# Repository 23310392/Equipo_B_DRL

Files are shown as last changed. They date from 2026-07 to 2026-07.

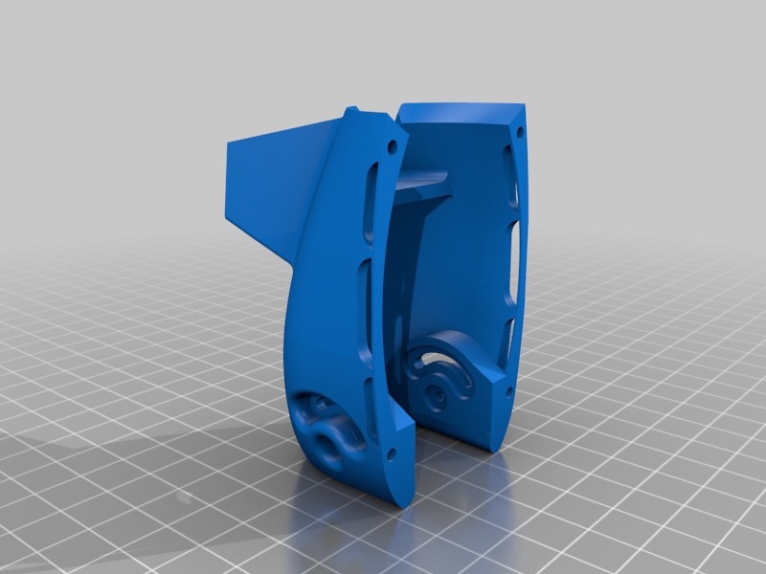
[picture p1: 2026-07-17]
Diseño 3D/Imagenes_Piezas_Diseño/6f083358760ed6dc125744b1c3c0a0e9.png

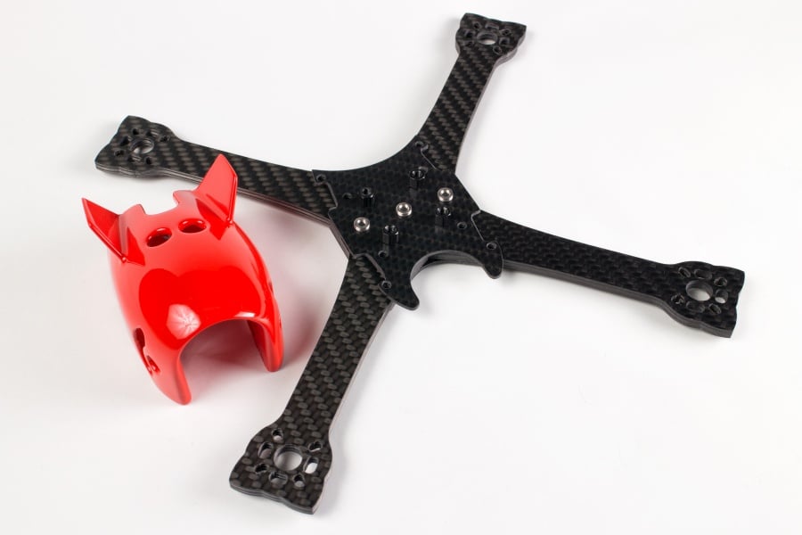
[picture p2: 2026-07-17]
Diseño 3D/Imagenes_Piezas_Diseño/IMG_6907.jpg

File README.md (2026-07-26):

<div align="justify">

# N.E.R.V. Protocol

INTEGRANTES:

* COVARRUBIAS SÁNCHEZ ESTEFHANY BETZABE - 23310387
* CORTES VILLA DANIEL - 23310392
* DURAN DE HUERTA JIMENEZ ALEX - 23310378
* FLORES GONZALEZ BYRON ZADQUIEL - 23310338
* TORRES HERNANDEZ ELIAS URIEL - 23310395

# Proyecto: Dron FPV Modificado (Ingeniería Inversa E88)

Este repositorio documenta todo el proceso de diseño, análisis, configuración y ensamblaje de un dron FPV personalizado. Este proyecto nace a partir de la aplicación de ingeniería inversa a un dron comercial modelo E88, con el objetivo de mejorar sus características de vuelo, adaptarlo para FPV (First Person View) y optimizar su rendimiento general.

---

## 📐 Diseño y Decisiones Estructurales

En esta sección se documentan las decisiones de diseño tomadas para llegar a la versión final del chasis y la distribución de componentes. 

<p align="justify">
<strong>MARK I</strong><br>
<strong>Reducción de peso y distribución de masa:</strong> El chasis fue diseñado con dimensiones inferiores a 5 pulgadas, optimizando la geometría para reducir el peso sin comprometer la rigidez estructural. La distribución de la masa se concentró en la parte central del dron para favorecer la estabilidad y mejorar la respuesta durante el vuelo.<br>
<strong>Materiales:</strong> El diseño está pensado para ser fabricado mediante impresión 3D en ABS, material que ofrece una buena relación entre resistencia mecánica, durabilidad y facilidad de fabricación. Esto permite obtener un prototipo ligero, resistente y de bajo costo para pruebas y validación.<br>
<strong>Integración de la electrónica:</strong> Este primer diseño se enfocó principalmente en el desarrollo de la estructura mecánica. No se definieron alojamientos ni puntos de montaje específicos para los componentes electrónicos, por lo que durante el ensamblaje se identificó que elementos como la batería, el Arduino Nano ESP32, el MPU6050, los ESC, el cableado y otros componentes no contaban con el espacio necesario para una integración adecuada. Estas limitaciones sirvieron como base para el rediseño de versiones posteriores.
</p>

<p align="center">
  Mark I
</p>

<p align="justify">
<strong>MARK II</strong><br>
<strong>Reducción de peso y distribución de masa:</strong> Para esta segunda iteración se realizó un rediseño completo del chasis tomando como referencia la arquitectura empleada en drones FPV de menos de 5 pulgadas. Se adoptó una configuración compuesta por una placa inferior, una cubierta superior y separadores, lo que permitió obtener una estructura más rígida y modular. Además, se buscó concentrar la mayor parte de la masa en la zona central del dron con el objetivo de mejorar la estabilidad, disminuir el momento de inercia y facilitar futuras tareas de mantenimiento y sustitución de componentes.<br>
<strong>Materiales:</strong> Al igual que en el MARK I, el prototipo fue diseñado para ser fabricado mediante impresión 3D en ABS. La elección de este material respondió a su buena resistencia mecánica, su capacidad para soportar impactos moderados y las temperaturas generadas durante la operación de los componentes electrónicos. Asimismo, el uso de impresión 3D permitió fabricar y evaluar rápidamente nuevas iteraciones del diseño, reduciendo los tiempos de desarrollo y el costo de fabricación de los prototipos.<br>
<strong>Diseño estructural:</strong> Durante esta iteración se incorporaron características propias de los chasis utilizados en drones FPV comerciales. Entre ellas destacan el soporte frontal para el montaje de la cámara, una cubierta superior desmontable para facilitar el acceso a la electrónica y una estructura interna pensada para organizar los diferentes módulos del sistema. Estas modificaciones representaron un avance significativo respecto al MARK I, ya que permitieron obtener un diseño más compacto, estético y cercano a una solución funcional.<br>
<strong>Integración de la electrónica:</strong> Una de las principales mejoras del MARK II fue la incorporación de espacios destinados al montaje de la batería y otros componentes electrónicos. Sin embargo, durante el proceso de ensamblaje se identificó que las dimensiones utilizadas durante el modelado no coincidían con las medidas reales de varios de estos componentes. Como consecuencia, algunos elementos no podían instalarse correctamente o requerían modificaciones adicionales para su montaje. Esta situación evidenció la importancia de realizar un levantamiento dimensional más preciso antes de la etapa de diseño, así como de considerar tolerancias de fabricación y ensamblaje. Las observaciones obtenidas durante esta fase sirvieron como base para el desarrollo del MARK III, donde se redimensionaron los compartimientos internos y se optimizó la distribución de los componentes para garantizar una integración adecuada.
</p>

<p align="center">
  Mark II
</p>

<p align="justify">
<strong>MARK III</strong><br>
<strong>Reducción de peso y distribución de masa:</strong> A diferencia de las iteraciones anteriores, en este diseño se decidió abandonar la restricción de construir un dron con dimensiones inferiores a 5 pulgadas. Durante el desarrollo se comprobó que los componentes electrónicos seleccionados requerían un mayor espacio para su integración, por lo que mantener ese límite comprometía tanto el ensamblaje como la distribución del peso. Como resultado, se diseñó un chasis completamente nuevo, con dimensiones personalizadas que permitieran alojar todos los componentes sin afectar la estabilidad ni la accesibilidad. La nueva distribución de masa se centró en mantener el centro de gravedad lo más cercano posible al eje del dron, favoreciendo un comportamiento estable durante el vuelo.<br>
<strong>Materiales:</strong> El chasis continúa siendo fabricado mediante impresión 3D en ABS, material seleccionado por su resistencia mecánica, durabilidad y facilidad de fabricación. El uso de este material permitió mantener un peso estructural relativamente bajo, además de facilitar la fabricación de piezas personalizadas y futuras modificaciones sin incrementar significativamente los costos del proyecto.<br>
<strong>Diseño estructural:</strong> El MARK III representa un rediseño completo respecto a los prototipos anteriores. Tanto la geometría como las dimensiones fueron desarrolladas específicamente para satisfacer las necesidades del proyecto, sin seguir estrictamente las medidas convencionales de los drones FPV comerciales. Se priorizó la funcionalidad sobre el tamaño, obteniendo un chasis más amplio que proporciona una mejor distribución interna, mayor facilidad de ensamblaje y acceso a los componentes para tareas de mantenimiento. Aunque sus dimensiones son mayores que las de los prototipos MARK I y MARK II, el diseño mantiene una estructura robusta, práctica y cómoda para su manipulación.<br>
<strong>Integración de la electrónica:</strong> Todas las dimensiones del chasis fueron ajustadas tomando como referencia las medidas reales de los componentes electrónicos. Esto permitió integrar correctamente la batería, el Arduino Nano ESP32, el MPU6050, los ESC, los motores, el sistema de distribución del cableado y los demás elementos necesarios para el funcionamiento del dron. A diferencia de las versiones anteriores, todos los componentes pueden instalarse sin interferencias mecánicas, facilitando el ensamblaje y el mantenimiento del sistema.<br>
<strong>Peso del prototipo:</strong> El chasis impreso y completamente ensamblado presenta un peso aproximado de 337 g. Una vez instalados todos los componentes electrónicos, el peso total del dron permanece por debajo de los 950 g, cumpliendo con el objetivo de mantener una plataforma suficientemente ligera para operar sin comprometer la resistencia estructural. Este equilibrio entre peso, espacio disponible y robustez convierte al MARK III en el diseño final del proyecto y en la versión que satisface completamente los requerimientos establecidos por el equipo.
</p>

---

## 📈 Modelado Matemático y Simulación en MATLAB

<p align="justify">
Para comprender el comportamiento dinámico del dron y predecir su respuesta a los comandos de control, se desarrolló un modelo matemático en MATLAB. A continuación se presenta la evidencia fotográfica y gráfica de las ondas de comportamiento de nuestro modelo (por ejemplo, respuesta al escalón, ajuste de PIDs teórico, estabilización de altitud).
</p>

### Diagrama de control
<p align="center">
  Diagrama de control
</p>

<p align="justify">
Este diagrama implementa un <strong>sistema de control en cascada</strong> para la estabilización y seguimiento de trayectoria de un modelo no lineal de 6 grados de libertad (<code>Modelo_NERV</code>) en Simulink.
</p>

### 📐 Arquitectura del Sistema
* **Control de Posición (Lazos Externos):** Regula las coordenadas de translación en los ejes $X$, $Y$ y la altura ($Z$), generando las referencias de actitud correspondientes.
* **Control de Actitud (Lazos Internos):** Estabiliza la orientación del vehículo gestionando los ángulos de **Roll** ($\phi$), **Pitch** ($\theta$) y **Yaw** ($\psi$).
* **Planta No Lineal:** Integra la dinámica de vuelo de 6-DOF (`Modelo_NERV`) junto con bloques de integración temporal y realimentación de estados.
* **Visualización:** Monitoreo en tiempo real de la posición espacial y el comportamiento de los ángulos de Euler mediante bloques *Scope*.

### Gráficas de movimiento (X, Y, Z, Roll, Pitch y Yaw)
<p align="justify">
<strong>Movimiento en X</strong>: Representa el desplazamiento lineal en el eje X. Se observa una transición limpia y rápida que alcanza la posición objetivo de 2m sin sobreimpulsos agresivos.
</p>
<p align="center">
  Gráfica de movimiento en X
</p>

<p align="justify">
<strong>Movimiento en Y</strong>: Muestra la respuesta en el eje Y alcanzando de forma estable y asintótica el valor de referencia configurado en 1m.
</p>
<p align="center">
  Gráfica de movimiento en Y
</p>

<p align="justify">
<strong>Movimiento en Z (Altura)</strong>: Muestra la respuesta escalón de la altitud del cuadricóptero. Presenta un ligero sobreimpulso controlado durante los primeros segundos antes de estabilizarse suavemente en la referencia deseada de 2m.
</p>
<p align="center">
  Gráfica de movimiento en Z
</p>

<p align="justify">
<strong>Ángulo Pitch</strong>: Ilustra la evolución del ángulo de cabeceo. Exhibe un pequeño transitorio inicial debido al acoplamiento dinámico antes de asentarse de manera completamente horizontal en estado estacionario.
</p>
<p align="center">
  Gráfica de ángulo Pitch
</p>

<p align="justify">
<strong>Ángulo Roll</strong>: Muestra el comportamiento del ángulo de alabeo. Presenta la compensación inicial de la inclinación lateral correspondiente al acoplamiento de los ejes antes de mantenerse estable en 0°.
</p>
<p align="center">
  Gráfica de ángulo Roll
</p>

<p align="justify">
<strong>Ángulo Yaw</strong>: Refleja la orientación del ángulo de guiñada, el cual converge de forma uniforme y estable hacia el valor de referencia establecido.
</p>
<p align="center">
  Gráfica de movimiento en Y
</p>

---

## ⚡ Electrónica y Protocolos de Comunicación

<p align="justify">
La transformación del E88 a un dron FPV funcional requirió una actualización completa de la electrónica y la implementación de protocolos de comunicación robustos.
</p>

### Componentes Principales
*   **Controladora de Vuelo (FC):** [Sensor MPU6050]
*   **Variadores de Velocidad (ESC):** [ESCs 30A]
*   **Motores:** [2212 1000KV]
*   **Receptor :** [Arduino nano ESP32]

### Protocolos de Comunicación Utilizados
*   **Receptor a Controladora (Arduino nano ESP32 -> dispositivo conectado por wifi):** El protocolo más común para conectar un Arduino Nano ESP32 a un dispositivo vía Wi-Fi y controlar un dron es el uso de comunicación basada en UDP/TCP sobre la red inalámbrica, donde el ESP32 actúa como punto de acceso o cliente y recibe comandos de control (pitch, roll, yaw, throttle) enviados desde un smartphone o computadora. Esto permite transmitir órdenes en tiempo real con baja latencia.
*   **Controladora(Arduino nano ESP32) a ESCs:** La comunicación entre el Arduino Nano ESP32 y los ESCs de 30A se realiza de forma simple y eficiente mediante PWM, permitiendo controlar la velocidad de los motores y, con ello, la estabilidad y maniobrabilidad del dron.
*   **Sensores Internos (Acelerómetro):**
  * El **MPU6050** integra un acelerómetro de 3 ejes que mide las aceleraciones lineales en tiempo real.
  * Permite detectar cambios en la posición y movimiento del dron, fundamentales para calcular la orientación (roll, pitch).
  * Su comunicación mediante protocolo **I²C** (líneas SDA y SCL) simplifica la conexión con el **Arduino Nano ESP32**.
  * El acelerómetro trabaja junto con el giroscopio para reducir errores de deriva y mejorar la precisión de los cálculos de estabilidad.

## Reporte de materiales y justificación

## Sensor MPU6050
### Descripción
<p align="justify">
El MPU6050 es un módulo que integra un acelerómetro de 3 ejes y un giroscopio de 3 ejes, ofreciendo un sistema de medición de 6 grados de libertad (6DOF). Se utiliza ampliamente en proyectos de drones por su capacidad de medir aceleraciones lineales y velocidades angulares en tiempo real.
</p>

### Justificación de uso en el dron
- Permite obtener datos de orientación y movimiento (roll, pitch, yaw).
- Mejora la estabilidad del vuelo, corrigiendo oscilaciones y vibraciones.
- Facilita la implementación de controladores PID, ajustando la velocidad de los motores para mantener equilibrio.
- Incluye un Digital Motion Processor (DMP) que procesa cálculos de orientación dentro del chip, reduciendo la carga del microcontrolador.
- Se comunica mediante I²C, lo que simplifica la integración con placas como Arduino o ESP32.

### Beneficios en la mejora del dron
- Vuelo más estable y controlado.
- Maniobras más suaves y precisas.
- Reducción de errores por deriva del giroscopio mediante fusión de datos con el acelerómetro.
- Flexibilidad para integrarse con otros sensores (GPS, barómetro, magnetómetro).

---

## Placa de desarrollo Arduino Nano ESP32
### Descripción
<p align="justify">
El Arduino Nano ESP32 es una placa compacta que combina la facilidad de uso del ecosistema Arduino con la potencia del microcontrolador ESP32. Ofrece conectividad inalámbrica integrada (Wi-Fi y Bluetooth), múltiples entradas/salidas digitales y analógicas, y capacidad de procesamiento superior en comparación con placas tradicionales como el Arduino Nano clásico.
</p>

### Justificación de uso en el dron
- Actúa como unidad de control principal, gestionando la lectura de sensores y el envío de señales a los motores.
- Su procesador dual-core permite ejecutar algoritmos de control en tiempo real, como filtros de fusión de datos y controladores PID.
- La conectividad Wi-Fi/Bluetooth facilita la comunicación remota para telemetría, control desde aplicaciones móviles o transmisión de datos.
- Compatible con librerías y entornos de programación de Arduino, lo que simplifica el desarrollo y la integración con otros módulos.
- Su tamaño reducido y bajo consumo energético lo hacen ideal para aplicaciones en drones ligeros.

### Beneficios en la mejora del dron
- Mayor capacidad de procesamiento para cálculos de estabilidad y navegación.
- Posibilidad de implementar funciones avanzadas como control remoto inalámbrico o envío de datos en tiempo real.
- Integración sencilla con sensores como el MPU6050, GPS y módulos de comunicación.
- Optimización del espacio y peso gracias a su formato compacto.
- Es un componente de bajo costo y alta disponibilidad, ideal para proyectos académicos y prototipos.

---

## Controlador de velocidad electrónico (ESC) 30A
### Descripción
<p align="justify">
El ESC de 30 amperios (30A) es un controlador de velocidad electrónico diseñado para regular la potencia suministrada a los motores brushless del dron. Convierte la señal de control proveniente del microcontrolador (Arduino Nano ESP32) en pulsos eléctricos adecuados para ajustar la velocidad y dirección de los motores.
</p>

### Justificación de uso en el dron
- Permite un control preciso de la velocidad de los motores, esencial para la estabilidad y maniobrabilidad del dron.
- Soporta hasta 30 amperios de corriente, adecuado para motores de tamaño medio utilizados en drones académicos o recreativos.
- Incluye funciones de protección contra sobrecorriente y sobrecalentamiento, aumentando la seguridad del sistema.
- Compatible con señales PWM estándar, facilitando la integración con placas de control como el Arduino Nano ESP32.
- Su tamaño compacto y peso ligero lo hacen ideal para aplicaciones aéreas.

### Beneficios en la mejora del dron
- Mejora la respuesta dinámica del dron al ajustar rápidamente la velocidad de los motores.
- Contribuye a un vuelo más estable y seguro, evitando daños por sobrecarga eléctrica.
- Permite implementar algoritmos de control avanzados (PID) para mantener equilibrio y realizar maniobras suaves.
- Asegura una distribución eficiente de energía, optimizando el rendimiento de la batería.

---

## Motor Brushless 2212 1000KV
### Descripción
<p align="justify">
El motor brushless 2212 1000KV es un motor eléctrico sin escobillas diseñado para aplicaciones aéreas como drones y cuadricópteros. El valor 1000KV indica que el motor gira aproximadamente a 1000 revoluciones por minuto (RPM) por cada voltio aplicado, lo que lo hace adecuado para un equilibrio entre potencia y eficiencia.
</p>

### Justificación de uso en el dron
- Proporciona la fuerza de empuje necesaria para levantar y mantener el dron en vuelo.
- Su diseño sin escobillas (brushless) ofrece mayor durabilidad, menor mantenimiento y mejor eficiencia energética en comparación con motores con escobillas.
- El rango de 1000KV es ideal para drones de tamaño medio, ya que permite un buen control de velocidad y estabilidad sin sacrificar autonomía.
- Compatible con controladores ESC de 30A, asegurando una integración confiable en el sistema de propulsión.
- Su tamaño compacto y peso ligero lo hacen adecuado para estructuras de drones académicos y recreativos.

### Beneficios en la mejora del dron
- Vuelo más estable y eficiente, gracias a su respuesta rápida y precisa.
- Mayor tiempo de vuelo, al optimizar el consumo de energía de la batería.
- Capacidad de carga adecuada, permitiendo transportar sensores y componentes adicionales sin comprometer el rendimiento.
- Durabilidad y confiabilidad.

---

## 💻 Programación y Lógica de Vuelo (Custom Firmware)

<p align="justify">
El "cerebro" de este dron no utiliza un firmware comercial prefabricado, sino que funciona con un controlador de vuelo personalizado programado desde cero para el microcontrolador ESP32.
</p>

* **Estación de Control Terrestre (Interfaz Web y WebSockets):** Para este proyecto, decidimos prescindir de un radio control físico tradicional debido a limitaciones de tiempo y presupuesto. En su lugar, el ESP32 está configurado como un Punto de Acceso (AP) que genera su propia red Wi-Fi y aloja una interfaz web construida en HTML, CSS y JavaScript. Elegimos esta arquitectura web por su inmensa practicidad y facilidad de implementación: nos permite pilotar el dron desde cualquier smartphone directamente en el navegador, sin necesidad de instalar aplicaciones de terceros. Para garantizar que los movimientos de los joysticks virtuales lleguen al dron sin retrasos perceptibles, la comunicación bidireccional se realiza mediante el protocolo WebSockets.

* **Fusión de Sensores (Filtro Complementario):** Para que el dron "sienta" su orientación en el espacio, el ESP32 se comunica mediante el protocolo I2C con un sensor IMU MPU-6050. El código implementa un Filtro Complementario matemático que fusiona las lecturas rápidas del giroscopio con la referencia absoluta de la gravedad del acelerómetro, eliminando el ruido mecánico y el drift (desviación) a lo largo del tiempo.

* **Lazo de Control PID:** El corazón del vuelo autónomo es nuestro bucle PID (Proporcional, Integral, Derivativo), diseñado para ejecutarse a alta velocidad (aprox. 100Hz). El código compara constantemente la orientación real del dron (medida por el MPU-6050) con la orientación deseada por el piloto en la interfaz web. El PID calcula instantáneamente la compensación necesaria en los ejes de Cabeceo (Pitch), Alabeo (Roll) y Guiñada (Yaw) para corregir cualquier desviación.

* **Matriz de Mezcla de Motores (Mixer Quad-X):** Basándonos en la cinemática estándar de los drones cuadricópteros, los resultados del cálculo PID se introducen en un algoritmo de mezcla de motores. Este sistema distribuye matemáticamente la potencia necesaria a cada uno de los cuatro motores de forma independiente mediante señales PWM. Esto permite que el dron contrarreste la gravedad, obedezca los comandos direccionales y se estabilice a sí mismo frente a perturbaciones externas.

---

## 📸 Galería del Modelo Físico

<p align="justify">
En esta sección se muestra el resultado final del ensamblaje del dron, detallando el empaquetado de los componentes, la gestión de cables (cable management) y la estética final de la aeronave.

<p align="center">
WhatsApp Image 2026-07-25 at 9 10 56 PM
</p>
</p>

---

## Documento Post Mortem

<p align="justify">
Para la información completa de las fallas principales que presentó el dron MARK III y la razón de porqué no se logró realizar un vuelo de "hover", consulte el siguiente link:  <a href="./Post Mortem.md">Documento Post Mortem</a>. 
</p>
</div>

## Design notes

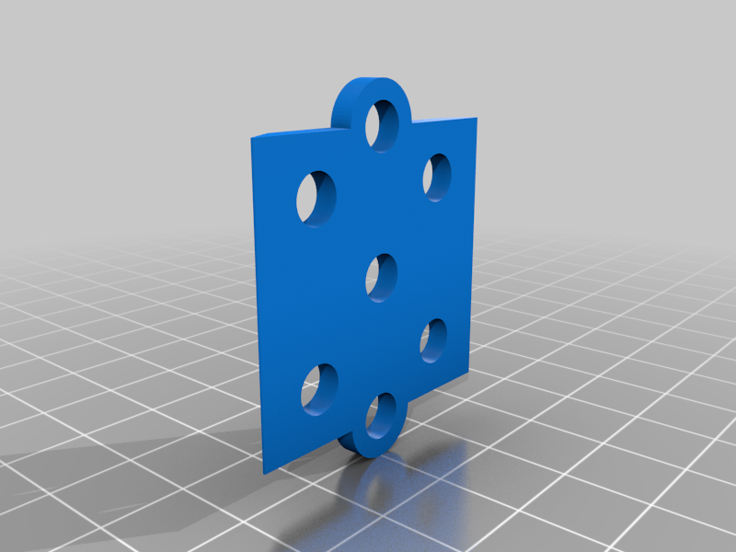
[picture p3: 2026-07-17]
Diseño 3D/Imagenes_Piezas_Diseño/4b94d525dbd86995620f139ecef4ba84.png

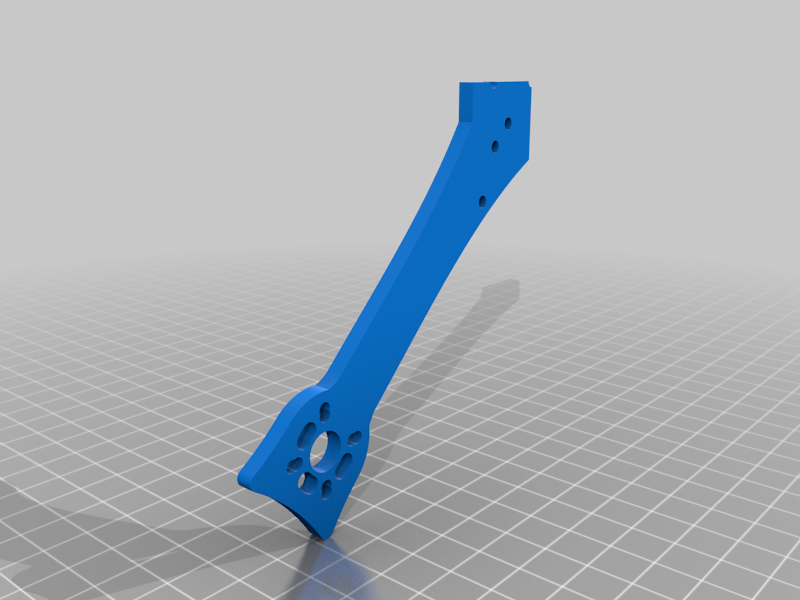
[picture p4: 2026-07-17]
Diseño 3D/Imagenes_Piezas_Diseño/7501a97a94f46a22147aaab2897a6f8f.png

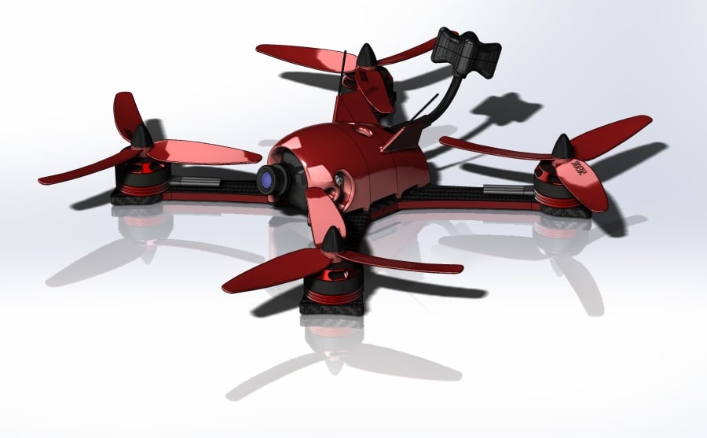
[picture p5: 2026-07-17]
Diseño 3D/Imagenes_Piezas_Diseño/3D.jpg

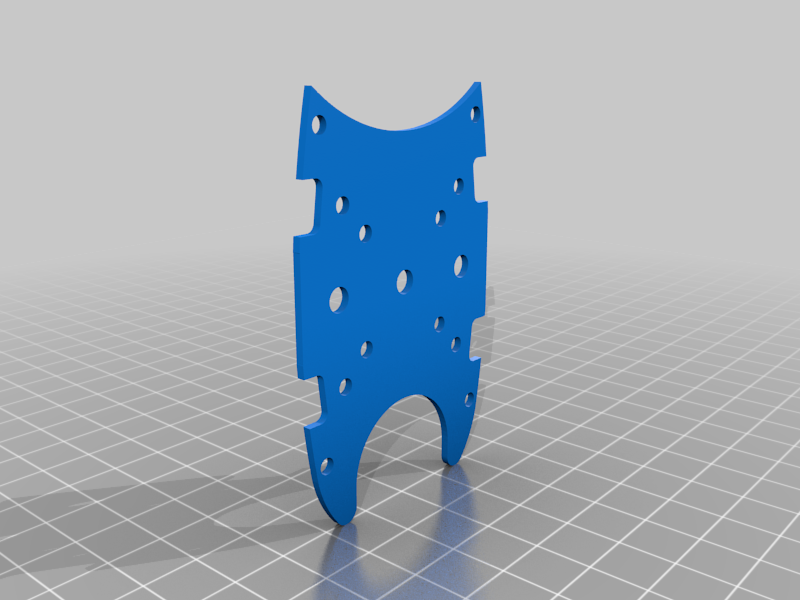
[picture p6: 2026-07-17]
Diseño 3D/Imagenes_Piezas_Diseño/b3bf354e30d19776aa43e7a58f74e8df.png

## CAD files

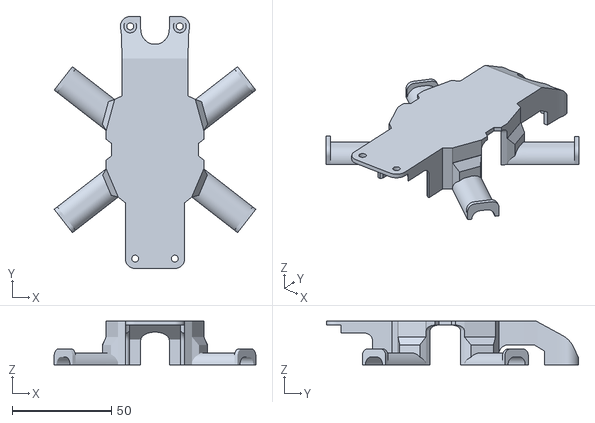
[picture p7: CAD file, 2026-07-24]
Diseño 3D/MARK II/canopi_without_camera_mount.stl
101.8 x 127.2 x 22.0

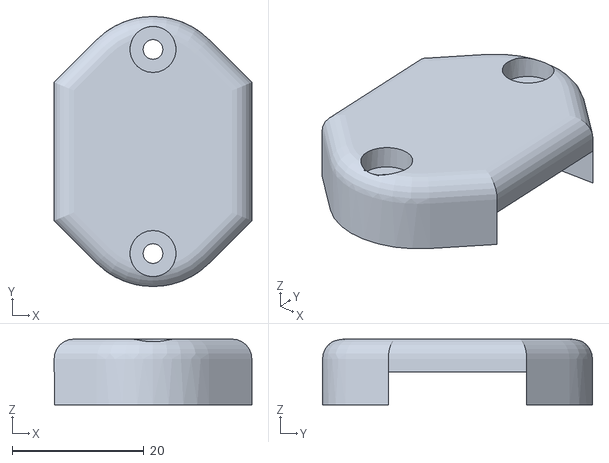
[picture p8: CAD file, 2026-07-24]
Diseño 3D/MARK III/pata 1.stl
30.0 x 41.0 x 10.0

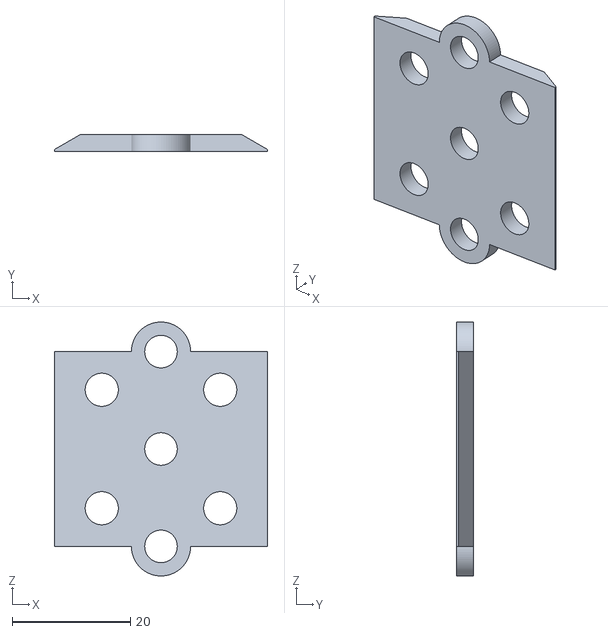
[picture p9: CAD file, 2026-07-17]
Diseño 3D/Piezas STL/batteryPad.STL
36.0 x 2.80 x 42.9

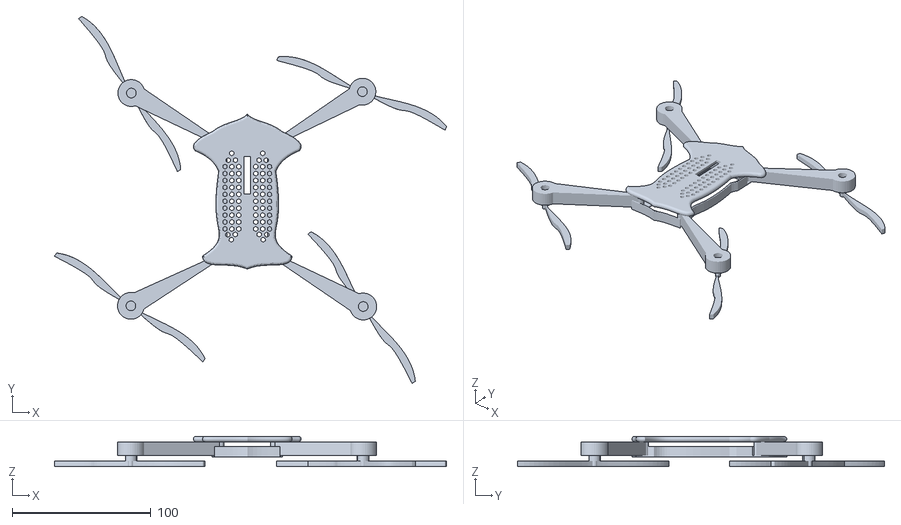
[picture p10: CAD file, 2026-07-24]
Gemelo Digital NERV/Dron_Equipo_A.STL
283.2 x 265.0 x 22.0

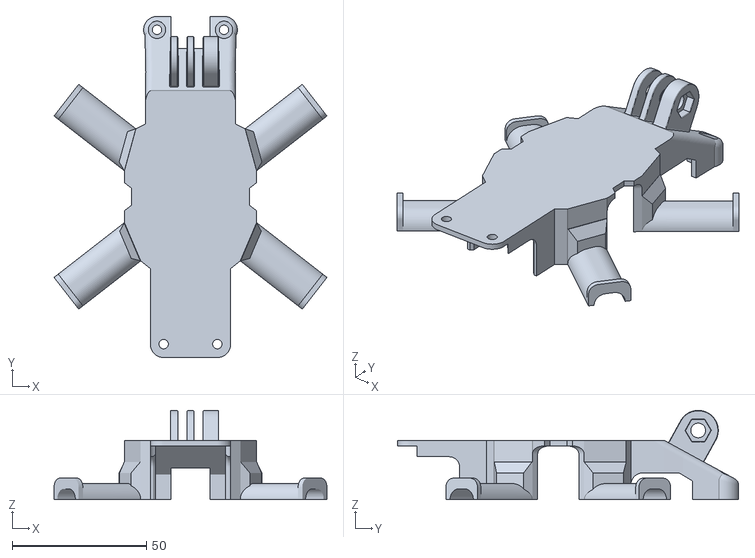
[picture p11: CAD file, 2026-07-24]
Diseño 3D/MARK II/canopi_with_gopro_compatible_mount.stl
101.8 x 127.2 x 33.3

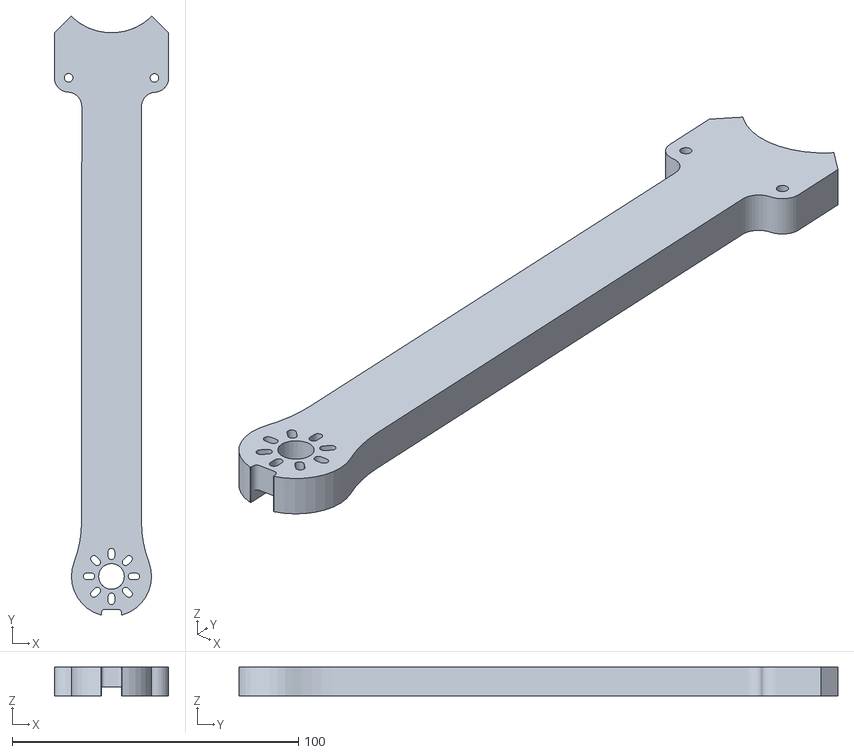
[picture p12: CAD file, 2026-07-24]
Diseño 3D/MARK III/ala 1.stl
40.0 x 209.4 x 10.00

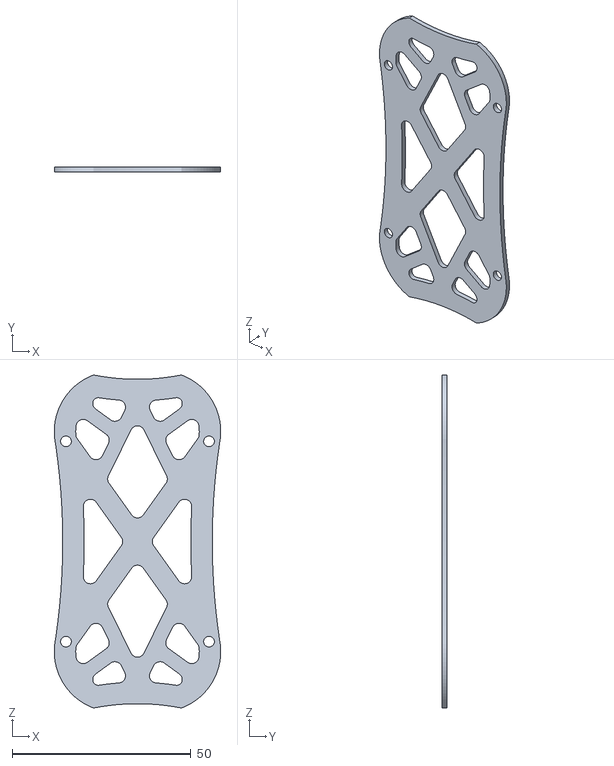
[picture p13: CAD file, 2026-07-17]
Diseño 3D/Piezas STL/battery_protector_v1.STL
46.5 x 1.50 x 93.1

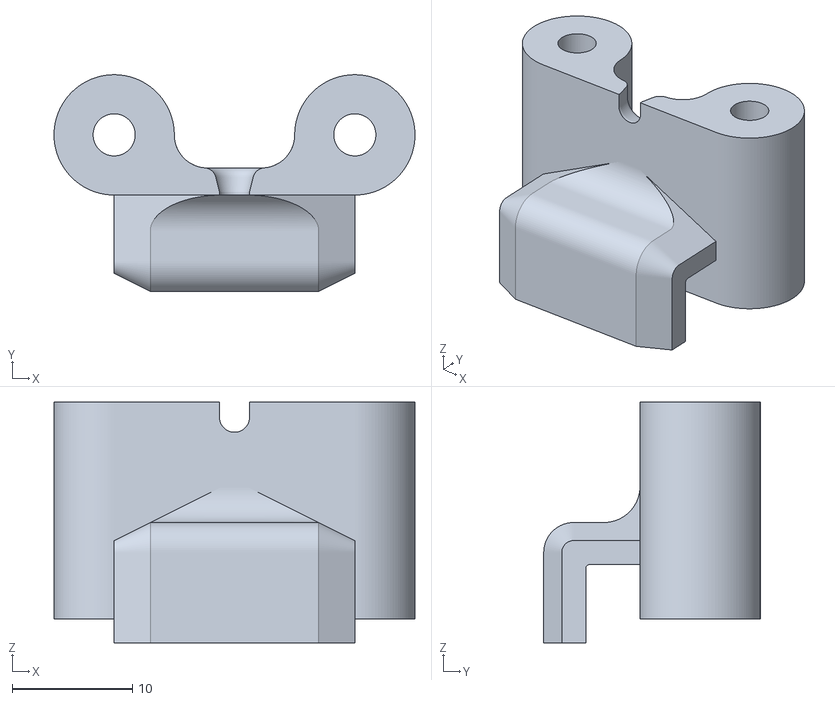
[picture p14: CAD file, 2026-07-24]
Diseño 3D/MARK II/posterior_standoff_with_the_minimortal_t_mount.stl
30.0 x 18.0 x 20.0

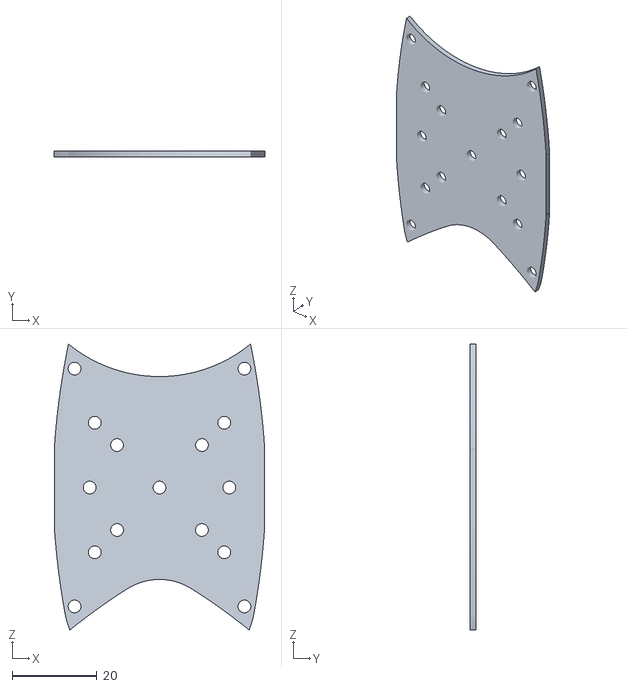
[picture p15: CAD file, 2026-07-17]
Diseño 3D/Piezas STL/base_bottom_v1.STL
49.6 x 1.50 x 67.3

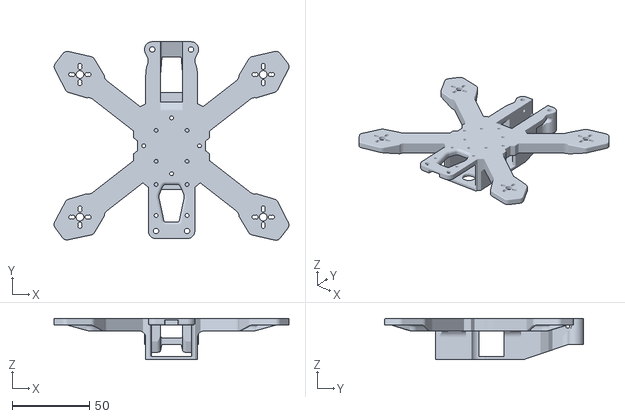
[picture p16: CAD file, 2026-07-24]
Diseño 3D/MARK II/bottom_piece.stl
151.8 x 128.3 x 26.8

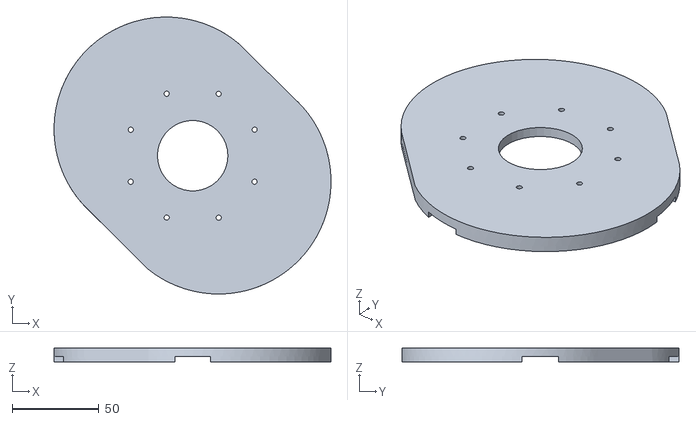
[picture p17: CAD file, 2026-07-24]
Diseño 3D/MARK III/base chasis.stl
159.9 x 159.9 x 8.00

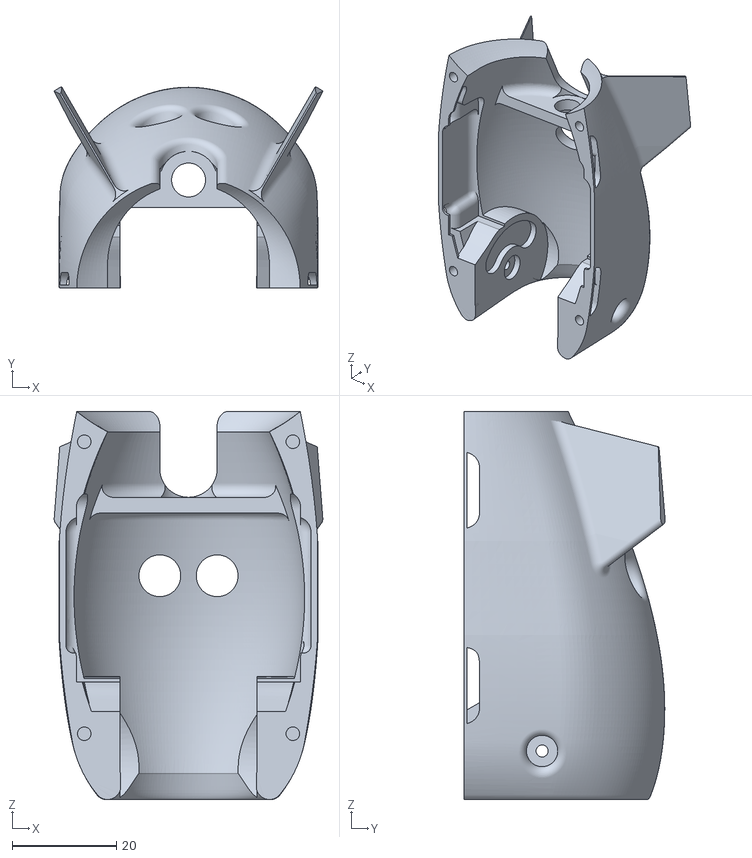
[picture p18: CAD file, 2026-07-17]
Diseño 3D/Piezas STL/shellV2.STL
51.5 x 38.6 x 74.4

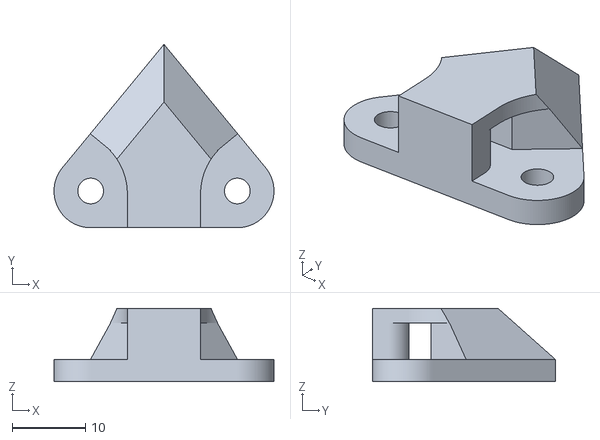
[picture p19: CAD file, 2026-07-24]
Diseño 3D/MARK II/antenna_mount.stl
30.0 x 25.0 x 10.0

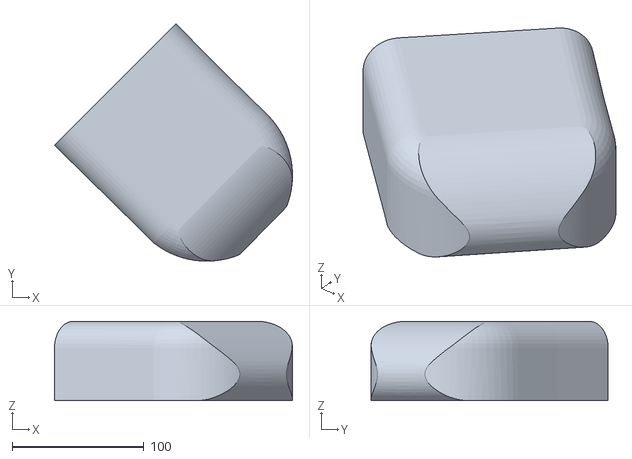
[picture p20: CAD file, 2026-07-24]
Diseño 3D/MARK III/chasis.stl
180.3 x 179.8 x 60.0

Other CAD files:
Diseño 3D/MARK III/ala 3.stl
Diseño 3D/Piezas STL/canopy_v1.STL
Diseño 3D/MARK II/canopi_with_generic_camera_mount.stl
Diseño 3D/MARK III/base.stl
Diseño 3D/MARK II/piece_pared_with_the_minimortal_t_standoff.stl
Diseño 3D/MARK II/posterior_standoff_without_the_minimortal_t_mount.stl
Diseño 3D/MARK III/ala 2.stl
Diseño 3D/MARK III/ala 4.stl
Diseño 3D/MARK III/pata 2.stl
Diseño 3D/MARK III/tapa chasis.stl
Diseño 3D/Piezas STL/base_top_v1.STL
Diseño 3D/Piezas STL/batteryPad2.STL
Diseño 3D/Piezas STL/boom_v1.STL
Diseño 3D/Piezas STL/stinger_carbon_parts_v1.DWG
Diseño 3D/Piezas STL/stinger_carbon_parts_v1.dxf

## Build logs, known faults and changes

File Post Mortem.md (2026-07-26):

<div align="justify">

# 📄 Análisis Post-Mortem: Proyecto N.E.R.V. Protocol

> **Nota:** Este documento detalla las causas técnicas, limitaciones operativas y fallos de integración por los cuales la plataforma física del dron N.E.R.V. Protocol no logró cumplir con los requisitos mínimos de desempeño para la demostración en vivo.

---

<div align="justify">

# 📄 Análisis Post-Mortem y Reporte Técnico de Integración: Proyecto N.E.R.V. Protocol

> **Estado del Documento:** Registro formal de fallas de integración, análisis de la dinámica de vuelo, limitaciones de manufactura aditiva y diagnóstico del sistema embebido. Este documento justifica por qué la plataforma física **MARK III** no logró cumplir los requisitos mínimos de despegue y estabilización en las pruebas finales.

---

## 📌 1. Resumen Ejecutivo y Marco Contextual

El proyecto **N.E.R.V. Protocol** tenía como objetivo la transformación e ingeniería inversa de un dron comercial de bajo costo (E88) hacia una plataforma FPV totalmente personalizada, controlada mediante una estación terrestre alojada en un microcontrolador **Arduino Nano ESP32** y un sensor IMU **MPU6050**. 

A pesar de haber desarrollado un modelo matemático congruente en Simulink —con control en cascada para la dinámica de 6 grados de libertad (6-DOF)— y de haber completado el ensamblaje físico del chasis **MARK III**, la plataforma no logró efectuar un despegue ni un vuelo estacionario controlado. 

Los factores determinantes de este fallo no fueron aislados; correspondieron a una **reacción en cadena de problemas multidominio**:
1. Desfases dimensionales por flexión y alabeo (*warping*) en la impresión 3D del chasis.
2. Incremento severo del momento de inercia que saturó los lazos de control PID.
3. Desincronización y asincronía en los controladores electrónicos de velocidad (ESCs).
4. Caídas de voltaje drásticas (*voltage sags*) bajo demanda de corriente de pico.
5. Ruido electromagnético que corrompió las lecturas del bus de datos I²C y la estabilidad de la red WebSockets.

---

## 🔍 2. Análisis Detallado de Causas Raíz

### 2.1. Desincronización y Respuesta Asíncrona del Sistema de Propulsión
Durante las pruebas de armado de motores y barridos de aceleración (*throttle ramps*), los cuatro motores *brushless* 2212 1000KV mostraron diferencias marcadas en el umbral de arranque y en la curva de aceleración lineal.
* **Mecanismo de Falla:** Las señales PWM generadas desde los pines del ESP32 presentaron variaciones temporales en el ancho de pulso debido a interrupciones internas del sistema operativo en tiempo real (FreeRTOS) al gestionar la pila del protocolo Wi-Fi. A esto se sumó la ausencia de un procedimiento de calibración simétrica individual para el rango de gas en los ESCs de 30A.
* **Efecto en la Dinámica:** En el momento en que se superaba el 40% del *throttle*, la fuerza de empuje ($T = C_T \cdot \rho \cdot n^2 \cdot D^4$) no crecía de forma uniforme en los cuatro vértices. Esta asimetría generaba un par de guiñada (*yaw torque*) y un momento de alabeo/cabeceo no deseado que volteaba la aeronave sobre su propio eje antes de romper la capa límite de suelo.

### 2.2. Penalización del Momento de Inercia por la Geometría MARK III
Las versiones previas (MARK I y MARK II) demostraron que intentar alojar la electrónica en un chasis de menos de 5 pulgadas generaba un empaquetamiento crítico e interferencias mecánicas. Para el MARK III se decidió romper la restricción dimensional y expandir los brazos para una mejor distribución.
* **Mecanismo de Falla:** El momento de inercia $I$ de un cuerpo rígido escala con el cuadrado de la distancia ($I = \int r^2 \, dm$). Al alejar los motores de 337 g (más los ESCs y cableado) del centro de masa, la inercia angular respecto a los ejes de Roll ($\phi$) y Pitch ($\theta$) creció exponencialmente.
* **Efecto en la Dinámica:** El controlador PID configurado en el firmware fue ajustado teóricamente para una respuesta inercial más rápida. Al encontrarse con una masa rotacional mucho mayor, el término Proporcional ($K_p$) generaba correcciones insuficientes, mientras que el término Derivativo ($K_d$) amplificaba el ruido de alta frecuencia, resultando en oscilaciones violentas de baja frecuencia (*prop wash* simulado) que volvían inestable el bucle de control.

### 2.3. Deformación por Manufactura Aditiva (Efecto de Alabeo en ABS)
El chasis del MARK III fue fabricado íntegramente en acrilonitrilo butadieno estireno (ABS) mediante modelado por deposición fundida (FDM). 
* **Mecanismo de Falla:** Durante la impresión de uno de los brazos principales, las corrientes de aire térmicas de la impresora generaron una contracción desigual del polímero en las capas inferiores (*warping*). Esto introdujo una elevación del plano del motor de aproximadamente 2.3° respecto al plano horizontal del chasis.
* **Efecto en la Dinámica:** La inclinación del eje de empuje ($T$) introdujo una componente vectorial parásita en el plano horizontal ($T_{xy} = T \cdot \sin(\theta_{error})$). Este vector descompuesto actuaba como una fuerza lateral constante que impulsaba al dron a realizar trayectorias circulares e inclinaciones laterales involuntarias. El filtro complementario intentaba nivelar el chasis basándose en la gravedad, pero al hacerlo, desviaba aún más el vector de empuje total de la vertical.

### 2.4. Colapso del Manejo de Potencia (*Voltage Sag*) y Alimentación
El dron requería elevar una masa total en orden de vuelo cercana a los 950 g, lo que exigía un empuje total mínimo de ~1900 g para mantener una relación empuje-peso ($T/W$) viable de 2:1.
* **Mecanismo de Falla:** Al acelerar los cuatro motores simultáneamente, el consumo de corriente escalaba rápidamente por encima de los 45 Amperios totales. La batería lipo utilizada no poseía la tasa de descarga constante ($C$-rating) suficiente para sostener esa demanda instantánea, ni se contaba con una Power Distribution Board (PDB) con reguladores aislados.
* **Efecto en la Dinámica:** La resistencia interna de la batería generaba una caída severa en la tensión de la línea principal (bajando de 12.6V a menos de 9.8V en picos). Esto provocaba que el regulador embebido del Arduino Nano ESP32 operara al límite de su umbral de caída (*drop-out*), causando reinicios aleatorios del sistema (*brownouts*), pérdida transitoria de paquetes en los WebSockets y caídas de la red Wi-Fi.

### 2.5. Acoplamiento Electromagnético y Ruido en Bus I²C
El microcontrolador y el módulo IMU MPU6050 se montaron en una placa perforada directamente sobre la ruta por donde circulaban los cables de alta corriente hacia los variadores ESC.
* **Mecanismo de Falla:** Las líneas del bus I²C (SDA y SCL) carecían de apantallamiento magnético y de resistencias de *pull-up* ajustadas para entornos ruidosos. Las conmutaciones rápidas de los transistores MOSFET de los ESCs inducían picos de fuerza electromotriz (FEM) de alta frecuencia en el cableado de señal.
* **Efecto en la Dinámica:** El bus I²C experimentaba bloqueos de comunicación (*bus freeze*) o inyección de valores basura en las lecturas del giroscopio y acelerómetro. El filtro complementario procesaba lecturas con aceleraciones espurias, interpretando que el dron estaba en una inclinación crítica cuando se encontraba nivelado, lo que hacía que el PID aplicara correcciones bruscas a los motores a través de la matriz de mezcla (*mixer*).

---

## 🛠️ 3. Matriz Auditiva de Diagnóstico y Puntos Críticos

Para documentar formalmente la auditoría ejecutada sobre la plataforma, se presenta la siguiente tabla de evaluación de subsistemas:

| Subsistema / Punto Crítico | Estado Detectado | Causa Técnica Primaria | Severidad | Acción Correctora Requerida |
| :--- | :--- | :--- | :--- | :--- |
| **Calibración IMU (MPU6050)** | Desviación de cero en los ejes Roll/Pitch | Calibración realizada sobre chasis deformado por impresión | 🔴 Alta | Calibrar IMU mediante plantilla metálica independiente del chasis. |
| **Matriz de Mezcla (Mixer Quad-X)** | Asignación de potencia asimétrica | Desalineación de los puntos muertos (*deadbands*) de PWM | 🔴 Alta | Implementar calibración eeprom de ESCs en paralelo con señal maestra. |
| **Centro de Gravedad (CG)** | Desplazado 14mm hacia el cuadrante posterior | Batería ubicada sin riel de ajuste longitudinal | 🟡 Media | Rediseñar bandeja de batería en el eje central de simetría $X$-$Y$. |
| **Filtro de Fusión de Datos** | Deriva rápida durante la aceleración | Ruido mecánico de las hélices transmitido al giroscopio | 🔴 Alta | Implementar soporte antivibración (*gimbal dampeners*) y Filtro Kalman. |
| **Aislamiento Electromagnético** | Picos de ruido en datos de sensores | Cables de potencia paralelos a líneas SDA/SCL de la IMU | 🟡 Media | Trenzar cables de potencia y aislar bus I²C con malla trenzada a tierra. |
| **Resistencia Estructural** | Flexión torsional en los brazos | Relleno de impresión (*infill*) por debajo del 40% en ABS | 🔴 Alta | Incrementar relleno al 70% o migrar estructura a placas de Fibra de Carbono. |

---

## 💡 4. Plan de Rediseño y Hoja de Ruta (MARK IV)

Para corregir integralmente las fallas documentadas y lograr una plataforma 100% funcional en futuras iteraciones, se establece el siguiente protocolo de ingeniería:

### 4.1. Optimización Estructural y Metrología
1. **Reducción de Escala:** Volver a una arquitectura geométrica "True-X" compacta con una distancia diagonal de motor a motor no mayor a 220 mm (5 pulgadas), reduciendo el momento de inercia ($I$) al menos en un 35%.
2. **Control de Calidad Dimensional:**
   * Utilizar un calibrador Vernier digital para validar tolerancias mecánicas en un rango de $\pm 0.05 \text{ mm}$ en los puntos de montaje de los motores.
   * Modificar el diseño CAD introduciendo filamentos de refuerzo en los vértices del chasis y prever un factor de contracción del $1.5\%$ para impresiones en ABS/PETG.
   * Implementar placas de amortiguación elástica (TPU) para aislar mecánicamente el soporte del Arduino Nano ESP32 y el sensor MPU6050 del chasis principal.

### 4.2. Reorganización de la Arquitectura Eléctrica
1. **Red de Distribución Integrada (PDB):** Incorporar una placa de distribución con dos circuitos BEC (Battery Eliminator Circuit) totalmente aislados:
   * **Línea de Potencia (12V ilimitado):** Conexión directa desde la batería de alta tasa de descarga ($>75C$) hacia los 4 ESCs.
   * **Línea Lógica (5V / 3A Regulado):** Conexión independiente con filtrado LC para alimentar el microcontrolador ESP32 y la IMU, eliminando *brownouts*.
2. **Filtrado de Ruido:** Soldar un capacitor electrolítico de bajo ESR (1000 µF / 25V) directamente en la entrada principal de la batería para absorber los picos de tensión inductivos (*voltage spikes*) provocados por el frenado regenerativo o aceleraciones del motor.

### 4.3. Refactorización del Firmware y Protocolos
1. **Calibración Simultánea de ESCs:** Escribir una rutina en la fase de inicialización del microcontrolador que envíe el pulso de ancho máximo ($2000 \, \mu\text{s}$) y mínimo ($1000 \, \mu\text{s}$) a los 4 canales PWM de forma sincronizada al energizar el sistema.
2. **Procesamiento de Señal Avanzado:** Sustituir el filtro complementario por un **Filtro de Kalman Extendido (EKF)** o implementar filtros muesca digitales (*Notch Filters*) dinámicos fijados en la frecuencia fundamental de rotación de los motores (~150-200 Hz).
3. **Optimización de Comunicaciones:** Migrar el envío de datos de control de WebSockets sobre TCP a un socket puro sobre **UDP**, evitando que el reenvío de paquetes perdidos bloquee la ejecución del bucle PID principal.

---

## 📋 5. Conclusiones

El desarrollo de las tres iteraciones sucesivas del dron MARK I, MARK II y MARK III demostró que el diseño de una aeronave no depende de la abstracción del software o del modelado conceptual en simuladores, sino de la interacción física real entre manufactura, eléctrica, dinámica de estructuras y señales.

El MARK III resolvió con éxito las restricciones de espacio físico y accesibilidad para mantenimiento que hacían inviables a los prototipos anteriores. Sin embargo, este sobredimensionamiento trasladó el problema hacia el dominio cinemático, la manufactura y la integridad eléctrica. 

Las fallas documentadas en este reporte constituyen el activo técnico más valioso del proyecto. El análisis de las causas raíz proporciona la base metrológica, electromecánica y de control necesaria para garantizar la estabilidad y viabilidad operativa en la versión MARK IV.

---

<p align="center">
  📂 <i>Este documento concluye el análisis técnico post-mortem del Proyecto N.E.R.V. Protocol.</i><br>
  ⬅️ <a href="./README.md">Volver al Repositorio Principal (README.md)</a>
</p>

</div>

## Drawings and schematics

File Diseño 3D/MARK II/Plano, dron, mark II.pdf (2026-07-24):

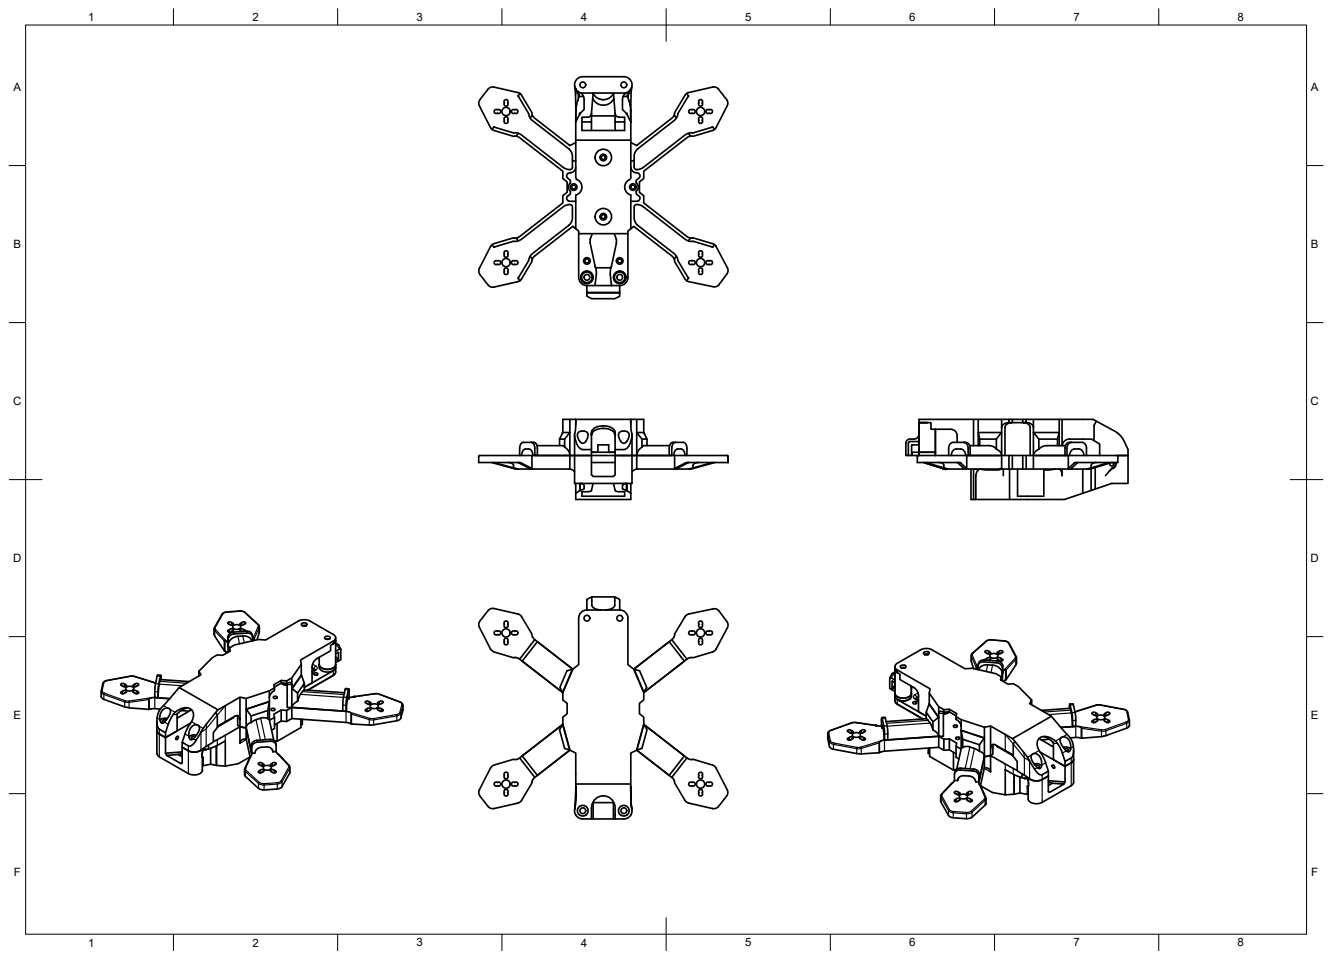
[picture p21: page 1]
8 BCDEF; ABCDEF

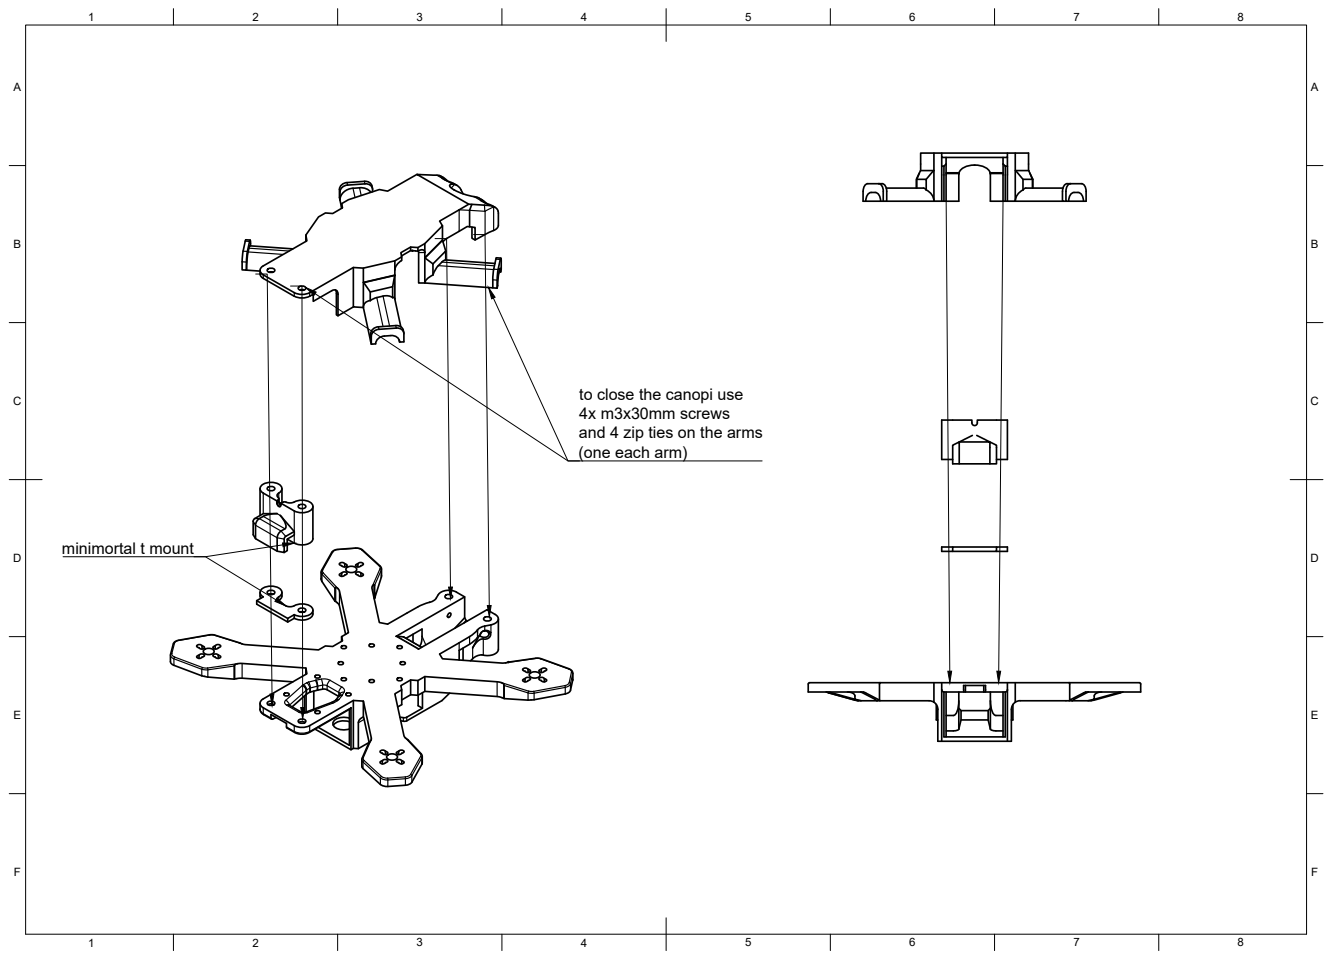
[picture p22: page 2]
minimortal t mount

to close the canopi use
4x m3x30mm screws
and 4 zip ties on the arms
(one each arm)

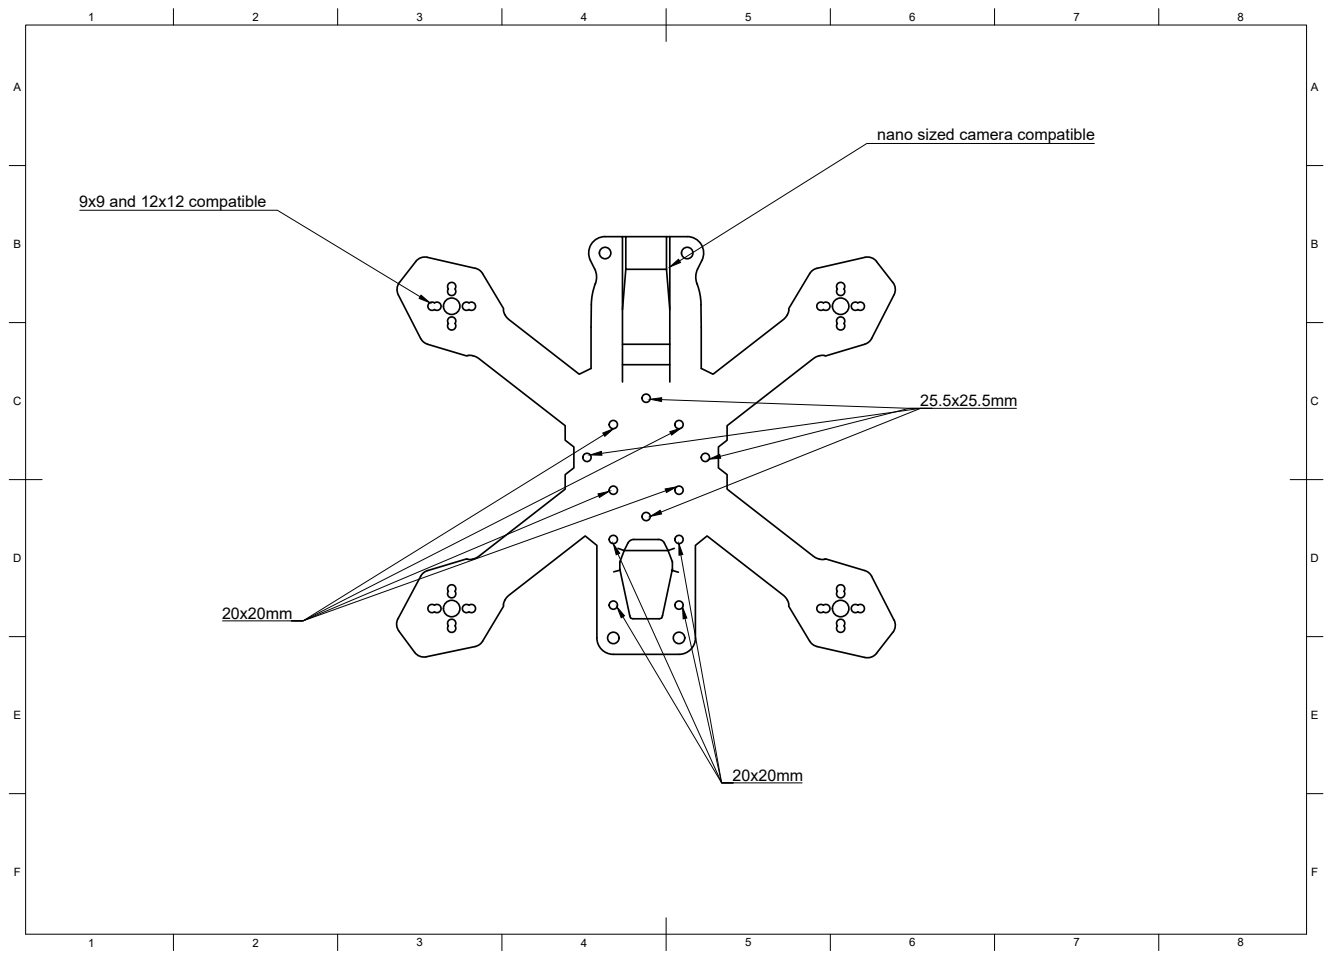
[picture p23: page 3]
9x9 and 12x12 compatible

nano sized camera compatible

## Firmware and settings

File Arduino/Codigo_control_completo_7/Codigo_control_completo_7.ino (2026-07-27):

#include <WiFi.h>
#include <WebServer.h>
#include <WebSocketsServer.h>
#include <Wire.h>
#include <ESP32Servo.h>

// --- CREDENCIALES WI-FI ---
const char* ssid = "NERV-Protocol";
const char* password = "sonotakus"; 

WebServer server(80);
WebSocketsServer webSocket = WebSocketsServer(81);

// --- DIRECCIÓN Y VARIABLES DEL MPU-6050 ---
const int MPU_ADDR = 0x68; 
int16_t AcX, AcY, AcZ, GyX, GyY, GyZ, Tmp;

// --- ASIGNACIÓN DE MOTORES (QUAD X) para Arduino Nano ESP32 ---
const int pinMotor1 = D2; // Trasero Derecho (CCW)
const int pinMotor2 = D3; // Frontal Derecho (CW)
const int pinMotor3 = D4; // Trasero Izquierdo (CW)
const int pinMotor4 = D5; // Frontal Izquierdo (CCW)

Servo esc1, esc2, esc3, esc4;

// --- VARIABLES DE ESTADO Y SEGURIDAD ---
enum DroneState { INICIANDO_ESCS, SUELO, DESPEGANDO, VOLANDO, ATERRIZANDO };
DroneState estadoDron = INICIANDO_ESCS;
bool mpuConectado = false; 
unsigned long tiempoInicioBoot = 0; 
unsigned long ultimaVezRecibido = 0; 

// Valores en microsegundos para los ESC
const int MIN_PULSE = 1000;
const int MAX_PULSE = 2000;
int pwmBase = MIN_PULSE;                 
const int PWM_HOVER = 1450; 
const int VELOCIDAD_RAMPA = 2; 

// --- VARIABLES DE CONTROL (Joysticks) ---
int throttleManual = 0, yawManual = 0, pitchManual = 0, rollManual = 0;

// --- VARIABLES DEL FILTRO COMPLEMENTARIO Y PID ---
unsigned long tiempoAnterior = 0;
float dt;

float pitchReal = 0, rollReal = 0;
float pitchTarget = 0, rollTarget = 0, yawTarget = 0;

// Constantes PID
float Kp = 2.5, Ki = 0.05, Kd = 18.0; 
float Kp_yaw = 3.0, Ki_yaw = 0.05, Kd_yaw = 0.0;

float errorPitch = 0, errorPitchPrev = 0, sumErrorPitch = 0;
float errorRoll = 0, errorRollPrev = 0, sumErrorRoll = 0;
float errorYaw = 0, errorYawPrev = 0, sumErrorYaw = 0;

// --- INTERFAZ WEB ---
const char index_html[] PROGMEM = R"rawliteral(
<!DOCTYPE html>
<html lang="es">
<head>
    <meta charset="UTF-8">
    <meta name="viewport" content="width=device-width, initial-scale=1.0, maximum-scale=1.0, user-scalable=no">
    <title>GCS Dron ESP32</title>
    <style>
        body { margin: 0; padding: 0; background-color: #222; color: white; font-family: Arial, sans-serif; display: flex; flex-direction: column; height: 100vh; overflow: hidden; }
        #header { text-align: center; padding: 10px; background: #333; font-size: 14px; }
        #joystick-container { display: flex; justify-content: space-between; align-items: center; flex: 1; padding: 10px 30px; }
        .joystick-zone { width: 150px; height: 150px; background: rgba(255, 255, 255, 0.1); border-radius: 50%; position: relative; touch-action: none; border: 2px solid #555; }
        .knob { width: 50px; height: 50px; background: #00ff88; border-radius: 50%; position: absolute; top: 50px; left: 50px; pointer-events: none; }
        #knob-left { background: #ff4444; } 
        #center-control { display: flex; flex-direction: column; align-items: center; justify-content: center; }
        .btn-auto { width: 80px; height: 80px; border-radius: 50%; background: #007bff; border: 2px solid #0056b3; cursor: pointer; box-shadow: 0 4px 10px rgba(0,0,0,0.5); }
        .btn-auto:active { background: #0056b3; transform: scale(0.95); }
        .btn-label { margin-top: 10px; font-size: 14px; font-weight: bold; text-align: center; color: #ccc; }
    </style>
</head>
<body>
    <div id="header">
        <span id="status" style="color: red;">Desconectado</span> | 
        CMD: <span id="data-out">T:0 Y:0 P:0 R:0</span>
    </div>
    <div id="joystick-container">
        <div class="joystick-zone" id="zone-left"><div class="knob" id="knob-left"></div></div>
        <div id="center-control">
            <button class="btn-auto" id="btn-flight"></button>
            <div class="btn-label">Despegue/<br>Aterrizaje</div>
        </div>
        <div class="joystick-zone" id="zone-right"><div class="knob" id="knob-right"></div></div>
    </div>
    <script>
        let controlData = { T: 0, Y: 0, P: 0, R: 0 };
        let gateway = `ws://${window.location.hostname}:81/`;
        let websocket = new WebSocket(gateway);

        websocket.onopen = () => { document.getElementById('status').style.color = "lime"; document.getElementById('status').innerText = "Conectado"; };
        websocket.onclose = () => { document.getElementById('status').style.color = "red"; document.getElementById('status').innerText = "Desconectado"; };

        document.getElementById('btn-flight').addEventListener('touchstart', function(e) {
            e.preventDefault(); if (websocket.readyState === WebSocket.OPEN) { websocket.send("CMD:FLIGHT"); }
        });

        function setupJoystick(zoneId, knobId, isLeft) {
            const zone = document.getElementById(zoneId);
            const knob = document.getElementById(knobId);
            const center = 75;
            zone.addEventListener('touchmove', function(e) {
                e.preventDefault();
                let touch = e.targetTouches[0];
                let rect = zone.getBoundingClientRect();
                let x = touch.clientX - rect.left - center;
                let y = touch.clientY - rect.top - center;
                let distance = Math.sqrt(x*x + y*y);
                if (distance > center) { x = x * (center / distance); y = y * (center / distance); }
                knob.style.transform = `translate(${x}px, ${y}px)`;
                if (isLeft) { controlData.Y = Math.round((x / center) * 100); controlData.T = Math.round((-y / center) * 100); } 
                else { controlData.R = Math.round((x / center) * 100); controlData.P = Math.round((-y / center) * 100); }
            });
            zone.addEventListener('touchend', function(e) {
                knob.style.transform = `translate(0px, 0px)`;
                if(isLeft) { controlData.Y = 0; controlData.T = 0; } 
                else { controlData.R = 0; controlData.P = 0; }
            });
        }
        setupJoystick('zone-left', 'knob-left', true);
        setupJoystick('zone-right', 'knob-right', false);

        setInterval(() => {
            let payload = `T:${controlData.T} Y:${controlData.Y} P:${controlData.P} R:${controlData.R}`;
            document.getElementById('data-out').innerText = payload;
            if (websocket.readyState === WebSocket.OPEN) { websocket.send(payload); }
        }, 50);
    </script>
</body>
</html>
)rawliteral";

void webSocketEvent(uint8_t num, WStype_t type, uint8_t * payload, size_t length) {
  if (type == WStype_TEXT) {
    ultimaVezRecibido = millis();

    if (strncmp((const char *)payload, "CMD:FLIGHT", 10) == 0) {
      if (estadoDron == SUELO && mpuConectado) estadoDron = DESPEGANDO;
      else if (estadoDron == VOLANDO || estadoDron == DESPEGANDO) estadoDron = ATERRIZANDO;
      return; 
    }
    int t, y, p, r;
    if (sscanf((const char *)payload, "T:%d Y:%d P:%d R:%d", &t, &y, &p, &r) == 4) {
      throttleManual = t; yawManual = y; pitchManual = p; rollManual = r;
    }
  }
}

void setup() {
  Serial.begin(115200);

  // 1. INICIAR COMUNICACIONES
  Serial.println("Iniciando Dron AP...");
  WiFi.softAP(ssid, password);
  Serial.print("Direccion IP del Dron: ");
  Serial.println(WiFi.softAPIP());
  
  server.on("/", []() { server.send(200, "text/html", index_html); });
  server.begin();
  webSocket.begin();
  webSocket.onEvent(webSocketEvent);
  
  // 2. CONFIGURAR TIMERS Y ESCs
  ESP32PWM::allocateTimer(0);
  ESP32PWM::allocateTimer(1);
  ESP32PWM::allocateTimer(2);
  ESP32PWM::allocateTimer(3);

  esc1.setPeriodHertz(50);
  esc2.setPeriodHertz(50);
  esc3.setPeriodHertz(50);
  esc4.setPeriodHertz(50);

  esc1.attach(pinMotor1, MIN_PULSE, MAX_PULSE);
  esc2.attach(pinMotor2, MIN_PULSE, MAX_PULSE);
  esc3.attach(pinMotor3, MIN_PULSE, MAX_PULSE);
  esc4.attach(pinMotor4, MIN_PULSE, MAX_PULSE);
  
  // 3. INICIAR SENSOR MPU6050
  Wire.begin();
  Wire.beginTransmission(MPU_ADDR);
  if (Wire.endTransmission() != 0) {
    Serial.println("¡ERROR! MPU6050 no responde.");
    mpuConectado = false;
  } else {
    Wire.beginTransmission(MPU_ADDR); Wire.write(0x6B); Wire.write(0); Wire.endTransmission(true);
    Wire.beginTransmission(MPU_ADDR); Wire.write(0x1A); Wire.write(0x03); Wire.endTransmission(true);
    mpuConectado = true;
  }
  
  tiempoInicioBoot = millis();
  tiempoAnterior = micros();
  Serial.println("Arrancando. Iniciando rutina de CALIBRACION AUTOMATICA de ESCs (8 segundos)...");
}

void loop() {
  server.handleClient();
  webSocket.loop();

  if (!mpuConectado) {
    esc1.writeMicroseconds(MIN_PULSE); esc2.writeMicroseconds(MIN_PULSE);
    esc3.writeMicroseconds(MIN_PULSE); esc4.writeMicroseconds(MIN_PULSE);
    estadoDron = SUELO;
    return; 
  }

  // --- NUEVO: CALIBRACIÓN AUTOMÁTICA DE ESCs ---
  if (estadoDron == INICIANDO_ESCS) {
    unsigned long tiempoTranscurrido = millis() - tiempoInicioBoot;
    
    if (tiempoTranscurrido < 4000) {
      // 1. Enviar señal MÁXIMA durante los primeros 4 segundos
      esc1.writeMicroseconds(MAX_PULSE);
      esc2.writeMicroseconds(MAX_PULSE);
      esc3.writeMicroseconds(MAX_PULSE);
      esc4.writeMicroseconds(MAX_PULSE);
    } else if (tiempoTranscurrido < 8000) {
      // 2. Bajar a señal MÍNIMA por otros 4 segundos
      esc1.writeMicroseconds(MIN_PULSE);
      esc2.writeMicroseconds(MIN_PULSE);
      esc3.writeMicroseconds(MIN_PULSE);
      esc4.writeMicroseconds(MIN_PULSE);
    } else {
      // 3. Finalizar calibración
      estadoDron = SUELO;
      Serial.println("Calibracion completada. ESCs Armados y Listos para volar.");
    }
    return; // Sale del loop para no calcular PIDs mientras calibra
  }

  // --- FAILSAFE DE COMUNICACIÓN ---
  if (estadoDron == VOLANDO || estadoDron == DESPEGANDO) {
    if (millis() - ultimaVezRecibido > 1000) {
      Serial.println("¡CONEXION PERDIDA! Aterrizaje de emergencia...");
      throttleManual = 0; pitchManual = 0; rollManual = 0; yawManual = 0;
      estadoDron = ATERRIZANDO; 
    }
  }

  // --- LÓGICA DE VUELO ---
  unsigned long tiempoActual = micros();
  dt = (tiempoActual - tiempoAnterior) / 1000000.0; 

  if (dt >= 0.01) { // 100Hz
    tiempoAnterior = tiempoActual;

    Wire.beginTransmission(MPU_ADDR);
    Wire.write(0x3B);
    Wire.endTransmission(false);
    Wire.requestFrom(MPU_ADDR, 14, true);

    AcX = Wire.read() << 8 | Wire.read(); AcY = Wire.read() << 8 | Wire.read(); AcZ = Wire.read() << 8 | Wire.read();
    Tmp = Wire.read() << 8 | Wire.read();
    GyX = Wire.read() << 8 | Wire.read(); GyY = Wire.read() << 8 | Wire.read(); GyZ = Wire.read() << 8 | Wire.read();

    float accPitch = atan2(AcY, AcZ) * 180 / PI;
    float accRoll  = atan2(-AcX, sqrt((long)AcY * AcY + (long)AcZ * AcZ)) * 180 / PI;

    float gyroXrate = GyX / 131.0;
    float gyroYrate = GyY / 131.0;
    float yawRate   = GyZ / 131.0;

    pitchReal = 0.98 * (pitchReal + gyroXrate * dt) + 0.02 * accPitch;
    rollReal  = 0.98 * (rollReal  + gyroYrate * dt) + 0.02 * accRoll;

    if (estadoDron == DESPEGANDO) {
      pwmBase += VELOCIDAD_RAMPA;
      if (pwmBase >= PWM_HOVER) { pwmBase = PWM_HOVER; estadoDron = VOLANDO; }
    } else if (estadoDron == ATERRIZANDO) {
      pwmBase -= VELOCIDAD_RAMPA;
      if (pwmBase <= MIN_PULSE) { pwmBase = MIN_PULSE; estadoDron = SUELO; }
    }

    int pwmFinalM1 = MIN_PULSE, pwmFinalM2 = MIN_PULSE;
    int pwmFinalM3 = MIN_PULSE, pwmFinalM4 = MIN_PULSE;

    if (estadoDron != SUELO) {
      pitchTarget = map(pitchManual, -100, 100, -20, 20);
      rollTarget  = map(rollManual, -100, 100, -20, 20);
      yawTarget   = map(yawManual, -100, 100, -45, 45); 
      
      int t_pwm   = map(throttleManual, -100, 100, -200, 200); 

      errorPitch = pitchTarget - pitchReal;
      sumErrorPitch += errorPitch * dt;
      sumErrorPitch = constrain(sumErrorPitch, -50, 50); 
      float dErrorPitch = (errorPitch - errorPitchPrev) / dt;
      float pidPitch = (Kp * errorPitch) + (Ki * sumErrorPitch) + (Kd * dErrorPitch);
      errorPitchPrev = errorPitch;

      errorRoll = rollTarget - rollReal;
      sumErrorRoll += errorRoll * dt;
      sumErrorRoll = constrain(sumErrorRoll, -50, 50); 
      float dErrorRoll = (errorRoll - errorRollPrev) / dt;
      float pidRoll = (Kp * errorRoll) + (Ki * sumErrorRoll) + (Kd * dErrorRoll);
      errorRollPrev = errorRoll;

      errorYaw = yawTarget - yawRate; 
      sumErrorYaw += errorYaw * dt;
      sumErrorYaw = constrain(sumErrorYaw, -50, 50);
      float dErrorYaw = (errorYaw - errorYawPrev) / dt;
      float pidYaw = (Kp_yaw * errorYaw) + (Ki_yaw * sumErrorYaw) + (Kd_yaw * dErrorYaw);
      errorYawPrev = errorYaw;

      int base = pwmBase + t_pwm;

      pwmFinalM1 = base + pidPitch - pidRoll + pidYaw;
      pwmFinalM2 = base - pidPitch - pidRoll - pidYaw;
      pwmFinalM3 = base + pidPitch + pidRoll - pidYaw;
      pwmFinalM4 = base - pidPitch + pidRoll + pidYaw;

      pwmFinalM1 = constrain(pwmFinalM1, MIN_PULSE, MAX_PULSE);
      pwmFinalM2 = constrain(pwmFinalM2, MIN_PULSE, MAX_PULSE);
      pwmFinalM3 = constrain(pwmFinalM3, MIN_PULSE, MAX_PULSE);
      pwmFinalM4 = constrain(pwmFinalM4, MIN_PULSE, MAX_PULSE);
    } else {
      sumErrorPitch = 0; sumErrorRoll = 0; sumErrorYaw = 0;
      pwmBase = MIN_PULSE;
    }

    esc1.writeMicroseconds(pwmFinalM1);
    esc2.writeMicroseconds(pwmFinalM2);
    esc3.writeMicroseconds(pwmFinalM3);
    esc4.writeMicroseconds(pwmFinalM4);
  }
}

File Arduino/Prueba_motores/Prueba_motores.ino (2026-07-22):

/* Bldc Motor Speed Controller Using Arduino UNO And ESC and Potentiometer (ElectroiQ Lab)*/
#include <Servo.h>

Servo ESC; 
int Speed; 

void setup() {
  ESC.attach(9,1000,2000);   // attach ESC to pin 9 with 1000-2000µs pulse range
}

void loop() {
  Speed = analogRead(A0);                // read potentiometer (0-1023)
  Speed = map(Speed, 0, 1023, 0, 180);   // map to 0–180 (Servo library scale)
  ESC.write(Speed);                      // write value to ESC
}

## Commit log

2026-07-10 Prueba de commit
2026-07-11 Se convirtió a proyecto de Matlab
2026-07-15 Primer commit de reporte de avances
2026-07-17 Se añadió el primer control en el eje Z del dron; se modeló con un control PID
2026-07-17 Control PID del dron en el eje Z
2026-07-17 Diagrama del dron NERV Protocol
    El diagrama anterior era del dron de prueba, este es del definitivo
2026-07-17 Add files via upload
    Piezas del diseño del dron en formato STL.
    Se presentarán todas las piezas que conforman el diseño del dron en archivos STL, mostrando una imagen individual de cada componente para identificar su función y ubicación dentro de la estructura. A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
    [base_bottom_v1.STL, base_top_v1.STL, batteryPad.STL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]
2026-07-20 Prueba sobre actualizacion de cambios
2026-07-20 Reacomodo de carpeta arduino
2026-07-20 Prueba de mando desde pc
2026-07-20 Codigo de prueba leds
2026-07-20 Control eje X
    Se agregó el modelado para el control en el eje X
2026-07-20 Control completo del dron
    Se modelaron los comportamientos de los ejes X, Y y Z además de Roll, Pitch y Yaw
2026-07-20 Add files via upload
    Modelado completo del dron que incluye:
    Ejes X, Y y Z
    Ángulos Roll, Pitch y Yaw
2026-07-20 Add files via upload
    Actualización del código del bloque de función
2026-07-20 Add files via upload
    Modelado completo del dron NERV con control de:
    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
2026-07-20 Se añadió el modelo del dron
    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
2026-07-20 Se añadió el modelado del comportamiento del dron
    Modelado completo del dron NERV en los 6 GDL's con control de:
    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
2026-07-20 Se añadió el modelado del comportamiento del dron
    Modelado completo del dron NERV de los 6 GDL's con control de:
    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
2026-07-20 Diseño de modelado
    Sintonización fina de controladores PID de 6-DOF y acoplamiento del eje Z
    - Ajuste fino de las ganancias PID para los lazos de posición X e Y, eliminando sobreimpulsos iniciales y caídas transitorias.
    - Integración del lazo de control de altitud en el eje Z con parámetros de respuesta estables (P=9, I=8, D=2.7).
    - Actualización de la función en MATLAB `Modelo_NERV` con dinámica de 12 estados documentada y lógica de acoplamiento cruzado.
2026-07-22 Primer README
    Se creó el texto inicial para el archivo README
2026-07-23 Correcciones en sección de software
    Updated sections on programming and flight logic, replacing references to Betaflight with a custom firmware explanation. Added details on ground control station and sensor fusion.
2026-07-23 Se añadieron las imágenes del modelo de control
2026-07-23 Update README.md
    Se añadio el diagrama de control al README
2026-07-23 Update README.md
    inclusión de la información sobre la electrónica, protocolos de comunicación y justificación de por que se uso
2026-07-23 Update README.md
    Se añadieron las gráficas del comportamiento de todos los grados de libertad
2026-07-24 Create Dron-Mark II
    Segundo diseño para prototipo de dron. MARK II. Medida menor a 5 pulgadas.
2026-07-24 Add files via upload
    MARK II. Segundo prototipo para dron fpv, cumple con la normativa y mide menos de 5 pulgadas.
    [antenna_mount.stl, bottom_piece.stl, canopi_with_generic_camera_mount.stl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]
2026-07-24 Add files via upload
    MARK III. Diseño final del dron.
    [ala 1.stl, ala 2.stl, ala 3.stl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]
2026-07-24 Add files via upload
    MARK II. Segundo prototipo para dron fpv, cumple con las normativas y mide menos de 5 pulgadas.
    [antenna_mount.stl, bottom_piece.stl, canopi_with_generic_camera_mount.stl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]
2026-07-24 Add files via upload
    MARK III
    Tercer prototipo de dron desarrollado y optimizado de acuerdo con las necesidades del equipo. Este diseño incorpora mejoras respecto a las versiones anteriores y cumple con los requisitos funcionales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
    [ala 1.stl, ala 2.stl, ala 3.stl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]
2026-07-24 Fotos de Mark I y Mark II
